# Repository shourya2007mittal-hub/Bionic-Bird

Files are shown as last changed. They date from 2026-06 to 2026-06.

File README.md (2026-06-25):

# Bionic-Bird



I made a bionic butterfly based on a custom ESP32 Board that holds an IMU and a Barometer for control. Is has 2 Servos each servos control a Wing. It uses a 3.7V battery and one can control it through your phone via bluetooth.

## Features

- Base on ESP32 Module
- Has IMU (MPU_6050)
- Has a Barometer (BMP280)
- Uses 2 High torque Servoes
- Would have LED strips on the wings

## Components BOM

| Item | Quantity | Price (USD) | Source |
|---|---|---|---|
| PCBA | - | $129.29 | JLCPCB |
| PCB Shipping | - | $11.99 | JLCPCB |
| High Torque Servo | 2 | $22.04 (for 2) | https://robu.in/product/waveshare-2-3kg-dual-axis-serial-bus-servo/ |
| LED Strip | 1 | $3.82 | https://robu.in/product/5m-neon-light-dance-party-decor-light-neon-led-lamp-flexible-el-wire-rope-tube-waterproof-led-strip-only-el-wire-yellow/ |

## Cost Summary

| Item | Cost (USD) |
|---|---|
| PCBA | $129.29 |
| PCB Shipping | $11.99 |
| High Torque Servo (2 units) | $22.04 |
| LED Strip | $3.82 |

**Total Estimated Cost:** **$167.14**

### Schematic



###  PCB Design




### 3D Design








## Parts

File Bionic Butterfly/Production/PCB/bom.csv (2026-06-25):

Designator | Footprint | Quantity | Value | LCSC Part #
C1, C2, C3 | 0201 | 3 | 2u2
C10, C9 | 0201 | 2 | 0.1uf
C11, C18, C19 | 0201 | 3 | 10 uf
C12 | 0201 | 1 | 0.1 uf
C13, C14 | 0201 | 2 | 100 nf
C1X1, C2X1, C3X1, C4X1, C5(1UF)1, C6(100NF)1 | 0805 | 6 | C
C4, C6 | 0201 | 2 | 100n
C5 | 0201 | 1 | 22u
D1 | 0201 | 1 | LED
D2 | 0201 | 1 | D
F1 | 0201 | 1 | Polyfuse
J1 | USB_C_Receptacle_G-Switch_GT-USB-7010ASV | 1 | USB_C_Receptacle_USB2.0_16P
J10, J2 | JST_EH_B2B-EH-A_1x02_P2.50mm_Vertical | 2 | Conn_01x02_Pin
J11, J12 | JST_EH_B3B-EH-A_1x03_P2.50mm_Vertical | 2 | Conn_01x03_Pin
Q1 | SOT-23 | 1 | AO3401A
R1, R2 | 0201 | 2 | 33 R
R1(10K)1, R2(100R)1 | 0805 | 2 | R
R3, R4 | 0201 | 2 | 50K
R5 | 0603 | 1 | 100R
R6 | 0201 | 1 | 1K
SW1, SW2 | SW_SPST_PTS810 | 2 | SW_Push
U1 | SOT-23-6 | 1 | MT3608
U2 | TSOT-23-6 | 1 | AP63203WU
U3 | InvenSense_QFN-24_4x4mm_P0.5mm | 1 | MPU-6050
U4 | Bosch_LGA-8_2x2.5mm_P0.65mm_ClockwisePinNumbering | 1 | BMP280
U5 | ESP32-S3-WROOM-1 | 1 | ESP32-S3-WROOM-1

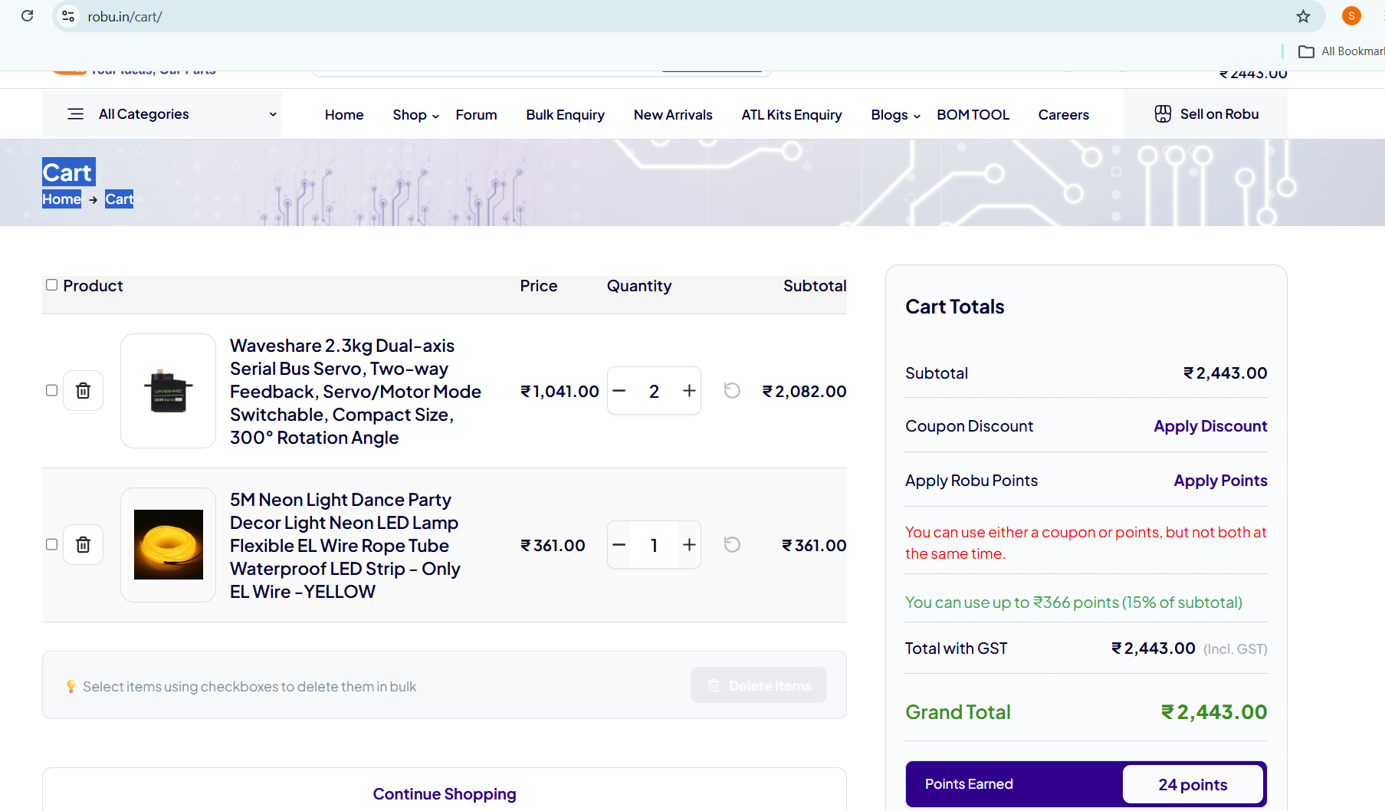
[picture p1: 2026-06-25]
Bionic Butterfly/Components-ScreenShots/Screenshot 2026-06-25 233311.png

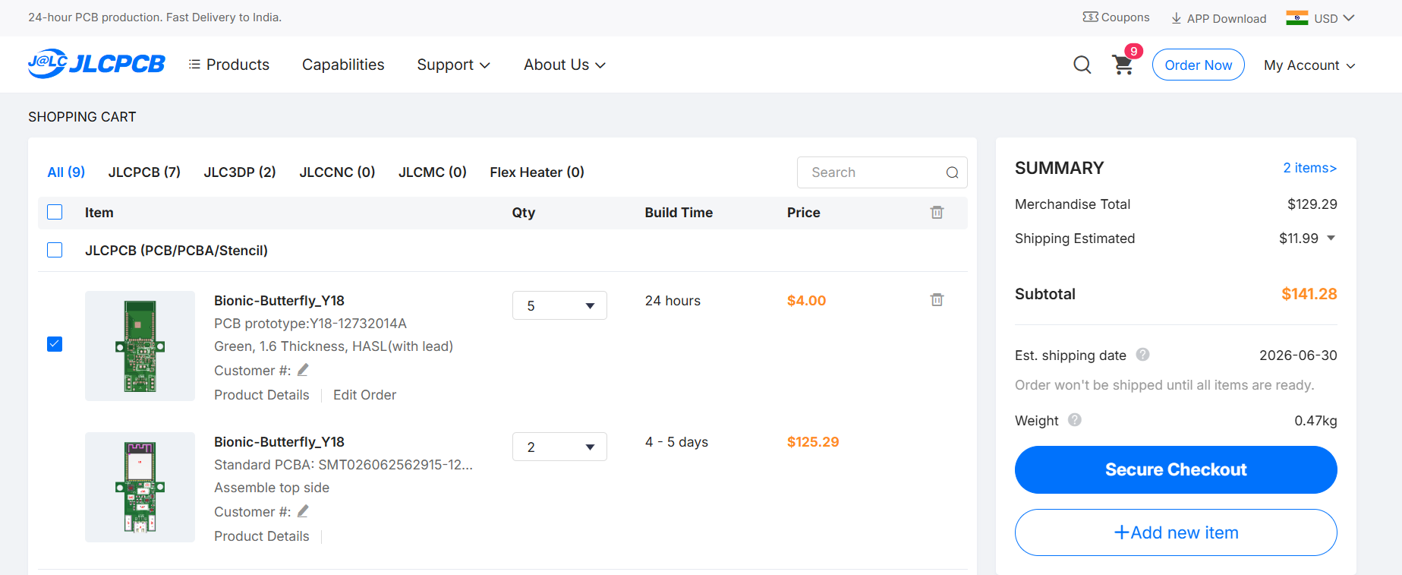
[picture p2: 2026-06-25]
Bionic Butterfly/Components-ScreenShots/Screenshot 2026-06-25 232757.png

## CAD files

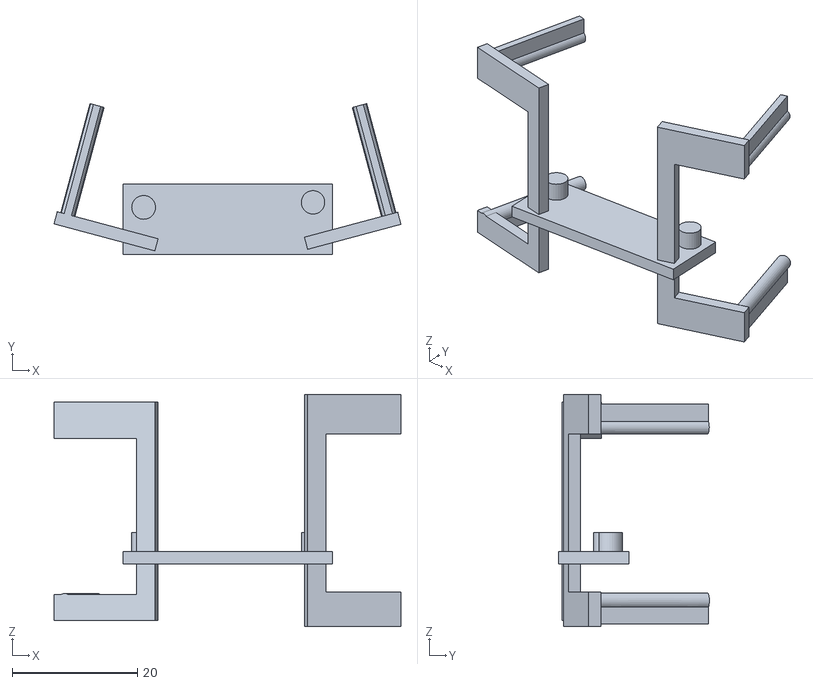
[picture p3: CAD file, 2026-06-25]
Bionic Butterfly/Production/CAD/MainBody.stl
55.3 x 24.0 x 37.0

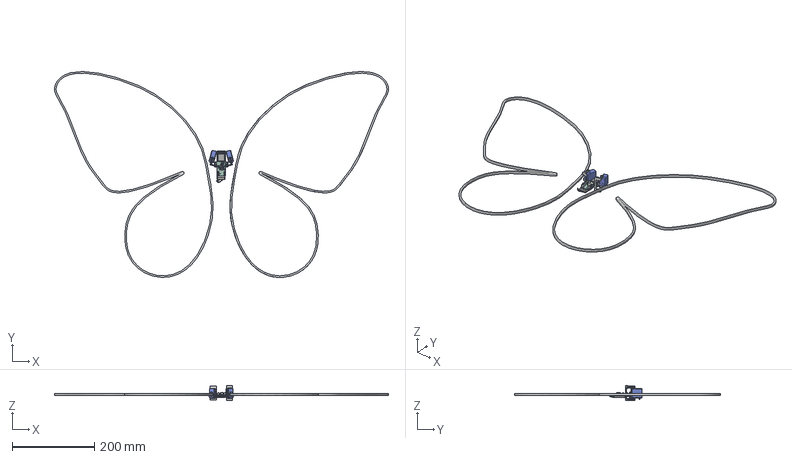
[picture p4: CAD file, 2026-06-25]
Bionic Butterfly/CAD/Bionic Butterfly.step
809.9 x 499.4 x 37.0 mm

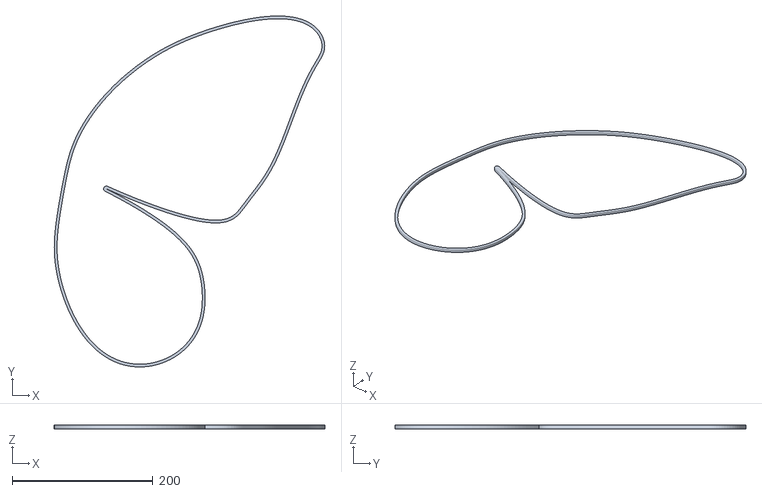
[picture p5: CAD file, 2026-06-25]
Bionic Butterfly/Production/CAD/RightWing.stl
384.9 x 499.4 x 5.00

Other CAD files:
Bionic Butterfly/Production/CAD/LeftWing.stl
Bionic Butterfly/CAD/Bionic Butterfly.f3d

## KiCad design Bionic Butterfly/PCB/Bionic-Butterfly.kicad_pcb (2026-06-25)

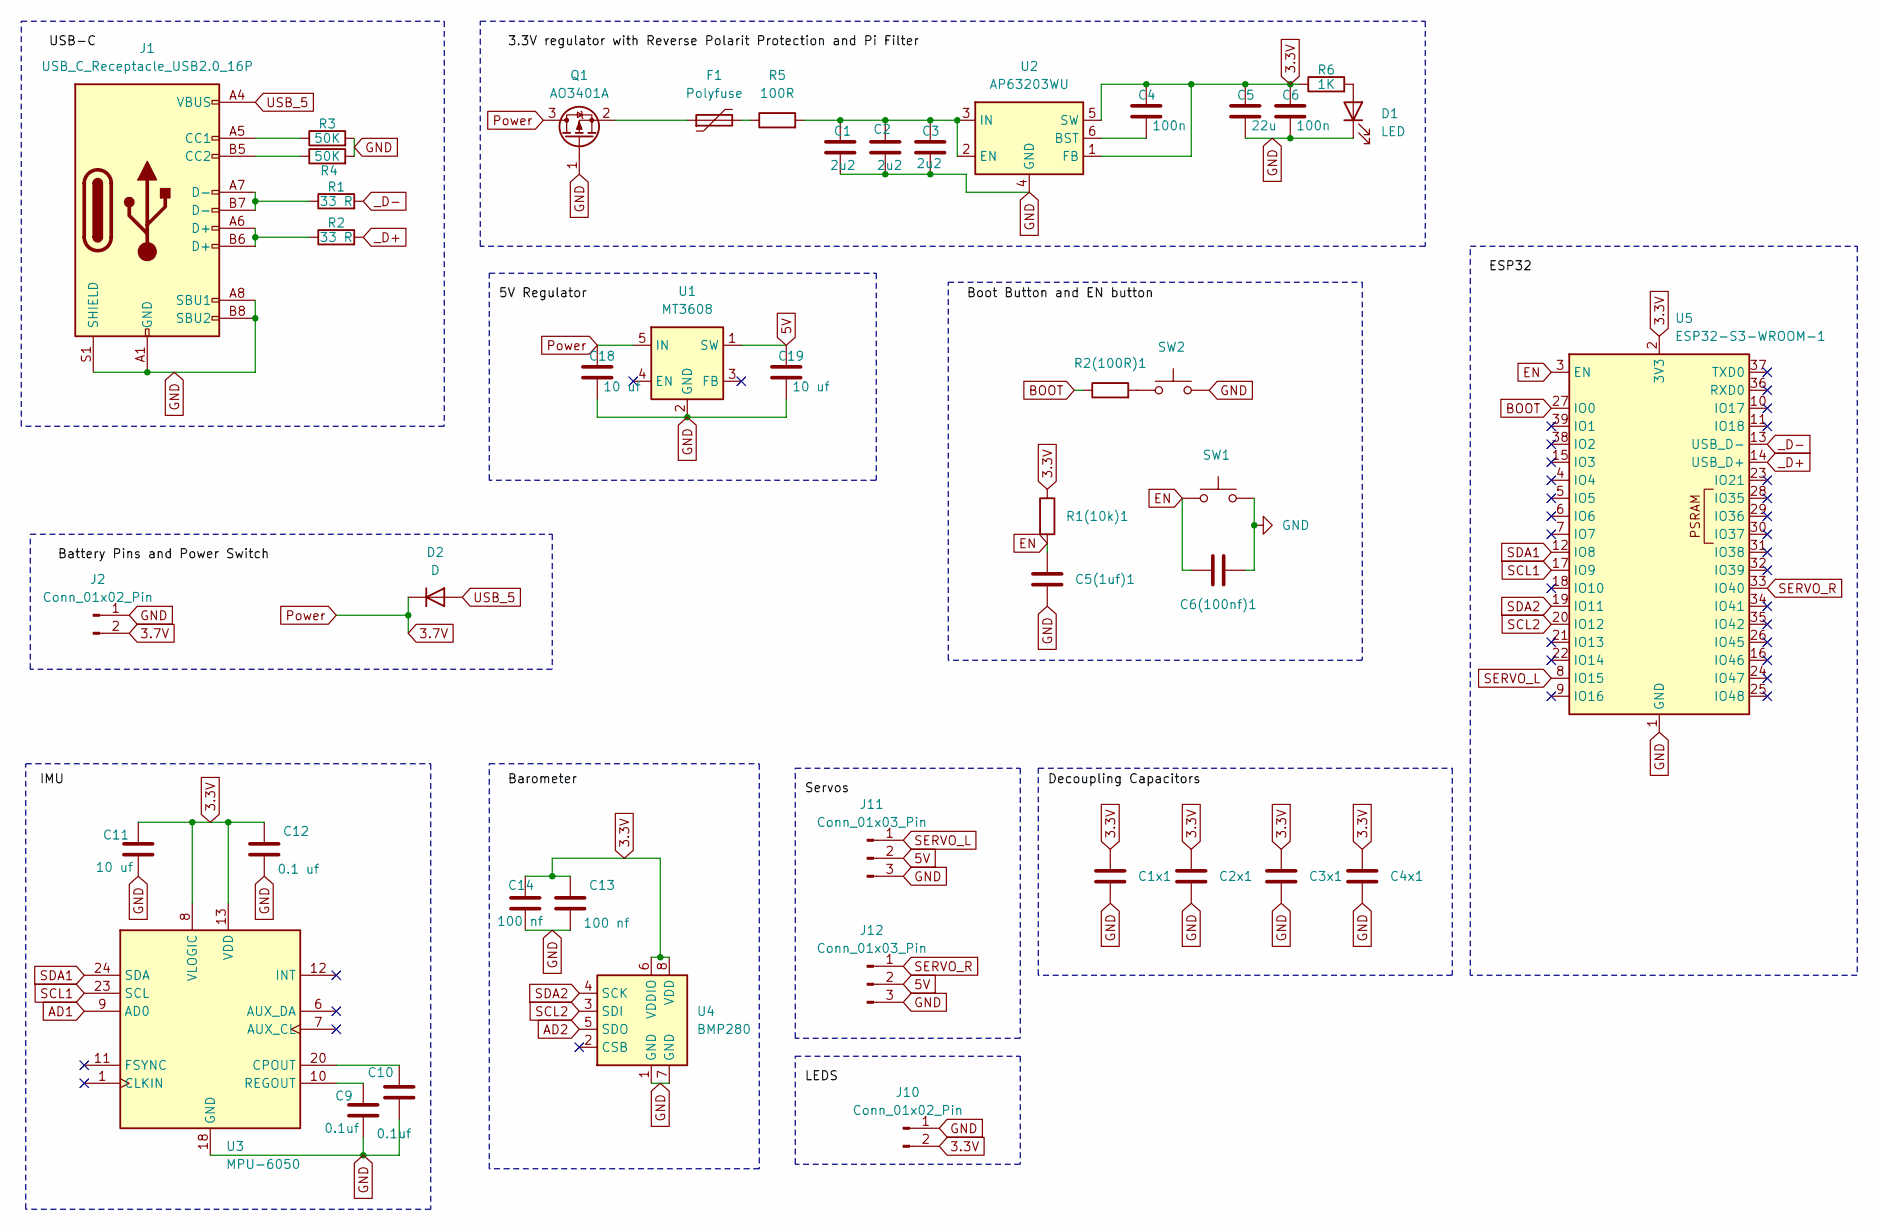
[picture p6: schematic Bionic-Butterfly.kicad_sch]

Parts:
C1, C2, C3: 2u2; C_0201_0603Metric
C1x1, C2x1, C3x1, C4x1, C5(1uf)1, C6(100nf)1: C; C_0805_2012Metric
C4, C6: 100n; C_0201_0603Metric
C5: 22u; C_0201_0603Metric
C9, C10: 0.1uf; C_0201_0603Metric
C11, C18, C19: 10 uf; C_0201_0603Metric
C12: 0.1 uf; C_0201_0603Metric
C13, C14: 100 nf; C_0201_0603Metric
D1: LED; LED_0201_0603Metric
D2: D; D_0201_0603Metric
F1: Polyfuse; C_0201_0603Metric
J1: USB_C_Receptacle_USB2.0_16P; USB_C_Receptacle_G-Switch_GT-USB-7010ASV
J2, J10: Conn_01x02_Pin; JST_EH_B2B-EH-A_1x02_P2.50mm_Vertical
J11, J12: Conn_01x03_Pin; JST_EH_B3B-EH-A_1x03_P2.50mm_Vertical
Q1: AO3401A; SOT-23
R1, R2: 33 R; R_0201_0603Metric_Pad0.64x0.40mm_HandSolder
R1(10k)1, R2(100R)1: R; R_0805_2012Metric
R3, R4: 50K; R_0201_0603Metric_Pad0.64x0.40mm_HandSolder
R5: 100R; R_0603_1608Metric
R6: 1K; R_0201_0603Metric_Pad0.64x0.40mm_HandSolder
SW1, SW2: SW_Push; SW_SPST_PTS810
U1: MT3608; SOT-23-6
U2: AP63203WU; TSOT-23-6
U3: MPU-6050; InvenSense_QFN-24_4x4mm_P0.5mm
U4: BMP280; Bosch_LGA-8_2x2.5mm_P0.65mm_ClockwisePinNumbering
U5: ESP32-S3-WROOM-1

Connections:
3.3V: C1x1.1, C2x1.1, C3x1.1, C4.1, C4x1.1, C5.1, C6.1, C11.1, C12.1, C13.1, C14.1, J10.2, R1(10k)1.1, R6.1, U2.1 (FB), U2.5 (SW), U3.8 (VLOGIC), U3.13 (VDD), U4.6 (VDDIO), U4.8 (VDD), U5.2 (3V3)
3.7V: C18.1, D2.1 (K), J2.2, Q1.3 (D), U1.5 (IN)
5V: C19.1, J11.2, J12.2, U1.1 (SW)
AD1: U3.9 (AD0)
AD2: U4.5 (SDO)
BOOT: R2(100R)1.1, U5.27 (IO0)
EN: C5(1uf)1.1, C6(100nf)1.1, R1(10k)1.2, SW1.1, U5.3 (EN)
GND: C1.2, C1x1.2, C2.2, C2x1.2, C3.2, C3x1.2, C4x1.2, C5.2, C5(1uf)1.2, C6.2, C6(100nf)1.2, C9.2, C10.2, C11.2, C12.2, C13.2, C14.2, C18.2, C19.2, D1.1 (K), J1.A1 (GND), J1.A8 (SBU1), J1.A12 (GND), J1.B1 (GND), J1.B8 (SBU2), J1.B12 (GND), J1.S1 (SHIELD), J2.1, J10.1, J11.3, J12.3, Q1.1 (G), R3.2, R4.2, SW1.2, SW2.2, U1.2 (GND), U2.4 (GND), U3.18 (GND), U4.1 (GND), U4.7 (GND), U5.1 (GND), U5.40 (GND), U5.41 (GND)
unnamed: D1.2 (A), R6.2
unnamed: F1.2, R5.1
unnamed: J1.A5 (CC1), R3.1
unnamed: J1.B5 (CC2), R4.1
unnamed: J1.A6 (D+), J1.B6 (D+), R2.1
unnamed: J1.A7 (D-), J1.B7 (D-), R1.1
unnamed: F1.1, Q1.2 (S)
unnamed: R2(100R)1.2, SW2.1
unnamed: C4.2, U2.6 (BST)
unnamed: C1.1, C2.1, C3.1, R5.2, U2.2 (EN), U2.3 (IN)
unnamed: C10.1, U3.20 (CPOUT)
unnamed: C9.1, U3.10 (REGOUT)
SCL1: U3.23 (SCL), U5.17 (IO9)
SCL2: U4.3 (SDI), U5.20 (IO12)
SDA1: U3.24 (SDA), U5.12 (IO8)
SDA2: U4.4 (SCK), U5.19 (IO11)
SERVO_L: J11.1, U5.8 (IO15)
SERVO_R: J12.1, U5.33 (IO40)
USB_5: D2.2 (A), J1.A4 (VBUS), J1.A9 (VBUS), J1.B4 (VBUS), J1.B9 (VBUS)
_D+: R2.2, U5.14 (USB_D+)
_D-: R1.2, U5.13 (USB_D-)

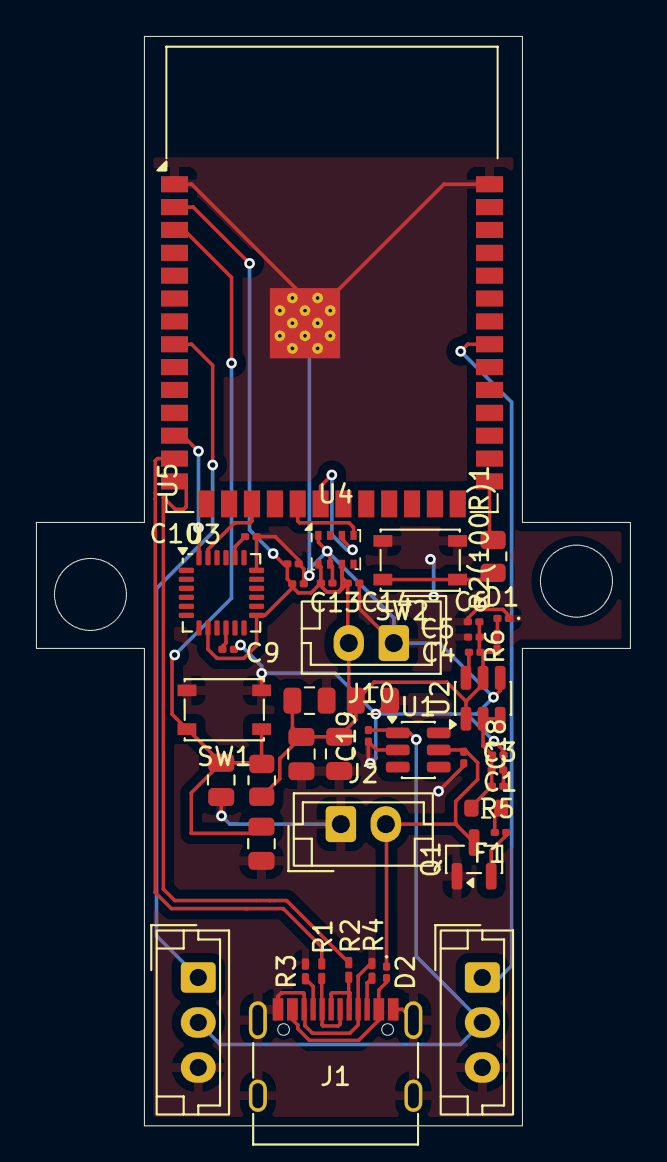
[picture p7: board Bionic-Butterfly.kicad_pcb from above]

Board: 2 copper layers, 33.0 x 60.5 mm, 44 parts (0 on the bottom side), 27 nets.

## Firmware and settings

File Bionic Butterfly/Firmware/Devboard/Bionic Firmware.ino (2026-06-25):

#include <Arduino.h>
#include <ESP32Servo.h>
#include <Wire.h>
#include <BLEDevice.h>
#include <BLEServer.h>
#include <BLEUtils.h>
#include <BLE2902.h>

// --- PIN CONFIGURATION ---
const int PIN_SERVO_L = 10;
const int PIN_SERVO_R = 40;
const int PIN_SDA      = 24;
const int PIN_SCL      = 23;

// --- FLIGHT CORE OBJECTS ---
Servo servoLeft;
Servo servoRight;

// --- BLE CONFIGURATION ---
#define SERVICE_UUID        "0000ffe0-0000-1000-8000-00805f9b34fb" 
#define CHARACTERISTIC_UUID "0000ffe1-0000-1000-8000-00805f9b34fb"

bool deviceConnected = false;
float targetRollInput = 0.0;   
float targetThrottleInput = 0.0; 

// --- IMU & PID FLIGHT DATA ---
const int MPU_ADDR = 0x68; 
float gyroX, gyroY; 
float pidOutputRoll = 0.0;
float pidOutputPitch = 0.0;

// PID Tuning Constants
const float Kp_Roll  = 0.8,  Kd_Roll  = 0.2;
const float Kp_Pitch = 0.5,  Kd_Pitch = 0.1;

float lastErrorRoll = 0.0;
float lastErrorPitch = 0.0;
unsigned long lastTime;

// --- ORNITHOPTER KINEMATICS CONFIGURATION ---
const int WING_CENTER_L      = 90;  
const int WING_CENTER_R      = 90;  
const float MAX_FLAP_FREQ    = 6.0; 
const float MAX_AMPLITUDE    = 40.0; 
float runningPhase = 0.0;           

class FlightServerCallbacks: public BLEServerCallbacks {
    void onConnect(BLEServer* pServer) { deviceConnected = true; }
    void onDisconnect(BLEServer* pServer) { deviceConnected = false; }
};

class FlightControlCallbacks: public BLECharacteristicCallbacks {
    void onWrite(BLECharacteristic *pCharacteristic) {
        std::string value = pCharacteristic->getValue();
        if (value.length() >= 2) {
            int8_t rawX = (int8_t)value[0];
            int8_t rawY = (int8_t)value[1];
            
            targetRollInput     = constrain(rawX / 100.0f, -1.0f, 1.0f);
            targetThrottleInput = constrain((rawY / 100.0f), 0.0f, 1.0f); 
        }
    }
};

void initMPU() {
    Wire.begin(PIN_SDA, PIN_SCL, 400000);
    Wire.beginTransmission(MPU_ADDR);
    Wire.write(0x6B); 
    Wire.write(0);    
    Wire.endTransmission(true);
}

void readIMUData() {
    Wire.beginTransmission(MPU_ADDR);
    Wire.write(0x43); 
    Wire.endTransmission(false);
    Wire.requestFrom(MPU_ADDR, 4, true);
    
    int16_t rawX = Wire.read() << 8 | Wire.read();
    int16_t rawY = Wire.read() << 8 | Wire.read();
    
    gyroX = rawX / 131.0f; 
    gyroY = rawY / 131.0f;
}

void setup() {
    Serial.begin(115200);
    lastTime = micros();

    ESP32PWM::allocateTimer(0);
    ESP32PWM::allocateTimer(1);
    servoLeft.setPeriodHertz(50);
    servoRight.setPeriodHertz(50);
    servoLeft.attach(PIN_SERVO_L, 500, 2500);
    servoRight.attach(PIN_SERVO_R, 500, 2500);

    initMPU();

    BLEDevice::init("BionicButterfly-FC");
    BLEServer *pServer = BLEDevice::createServer();
    pServer->setCallbacks(new FlightServerCallbacks());
    
    BLEService *pService = pServer->createService(SERVICE_UUID);
    BLECharacteristic *pChar = pService->createCharacteristic(
        CHARACTERISTIC_UUID,
        BLECharacteristic::PROPERTY_READ | BLECharacteristic::PROPERTY_WRITE | BLECharacteristic::PROPERTY_NOTIFY
    );
    
    pChar->setCallbacks(new FlightControlCallbacks());
    pChar->addDescriptor(new BLE2902());
    pService->start();
    
    pServer->getAdvertising()->start();
}

void loop() {
    unsigned long currentTime = micros();
    float dt = (currentTime - lastTime) / 1000000.0f;
    if (dt <= 0.0f) dt = 0.001f;
    lastTime = currentTime;

    readIMUData();

    float targetRollRate = targetRollInput * 40.0f; 
    float errorRoll = targetRollRate - gyroX;
    float derivRoll = (errorRoll - lastErrorRoll) / dt;
    pidOutputRoll = (Kp_Roll * errorRoll) + (Kd_Roll * derivRoll);
    lastErrorRoll = errorRoll;

    float errorPitch = (0.0f) - gyroY; 
    float derivPitch = (errorPitch - lastErrorPitch) / dt;
    pidOutputPitch = (Kp_Pitch * errorPitch) + (Kd_Pitch * derivPitch);
    lastErrorPitch = errorPitch;

    float activeFrequency = targetThrottleInput * MAX_FLAP_FREQ;
    float activeAmplitude = targetThrottleInput * MAX_AMPLITUDE;

    runningPhase += 2.0f * PI * activeFrequency * dt;
    if (runningPhase > 2.0f * PI) runningPhase -= 2.0f * PI;

    float baseFlapWave = sin(runningPhase);

    float commandL = WING_CENTER_L + (baseFlapWave * activeAmplitude) + pidOutputRoll + pidOutputPitch;
    float commandR = WING_CENTER_R - (baseFlapWave * activeAmplitude) + pidOutputRoll - pidOutputPitch;

    int safeServoPosL = constrain(round(commandL), 15, 165);
    int safeServoPosR = constrain(round(commandR), 15, 165);

    servoLeft.write(safeServoPosL);
    servoRight.write(safeServoPosR);

    delay(10); 
}
